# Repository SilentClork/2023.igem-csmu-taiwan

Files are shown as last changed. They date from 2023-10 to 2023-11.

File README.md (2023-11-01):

# 2023.igem-csmu-taiwan

**iGEM Hardware & Software Open-Source Project**
Welcome to the open-source hardware and software project by the CSMU-Taiwan team for the iGEM competition. Our aim is to provide a straightforward, reliable, and low-cost spectrophotometer solution that not only meets experimental requirements but also serves as an educational tool.

Project Structure and Content
**1. Espec - Professional Spectrophotometer Software**
EspecIonic:
An application developed with the Ionic framework, yet to be launched on the App Store or Google Play.

EspecWeb:
A version of Espec rewritten using HTML, its functionality is identical to the Ionic version.

Espec_User_Guide.pdf:
User guide for the Espec software.

**2. ver1_ResistanceMonitor_ArduinoR3 - Initial Hardware Design**
3D_Components:
3D design files for the first-generation hardware.

Arduino_Code:
Code for the Arduino Uno.

Assembly_Guide:
Assembly and usage guide for the hardware.

**3. ver2_LightMeasurement_ESP32 - Advanced Hardware Design**
3D_Components:
3D design files for the second-generation hardware.

Arduino_Code: Contains the code for the ESP32. This includes:
  - `ver2_LightMeasurement_ESP32.ino`: The initial version requiring Wi-Fi connectivity.
  - `ver2-2_LightMeasurement_ESP32_NoWIFI.ino`: An updated version that operates without the need for Wi-Fi connectivity, suitable for environments lacking network infrastructure.

Assembly_Guide:
Assembly and usage guide for the hardware.

**Open-Source License**
This project is licensed under the MIT License. For detailed information, please refer to the LICENSE.txt file.

**How to Contribute**
We eagerly look forward to your participation! If you have any suggestions or improvements for this project, please submit a pull request or open an issue.

**Contact Us**
If you have any questions or suggestions, please feel free to contact us via the following email: twcsmu.igem2023@gmail.com

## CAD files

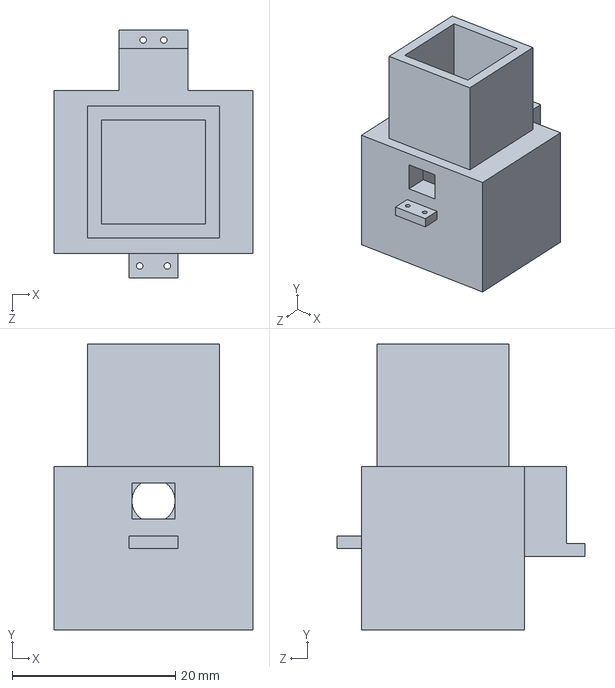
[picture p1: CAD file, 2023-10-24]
ver1_ResistanceMonitor_ArduinoR3/3D_Components/ver1-cuvette-slot.SLDPRT
24.3 x 35.0 x 30.4 mm

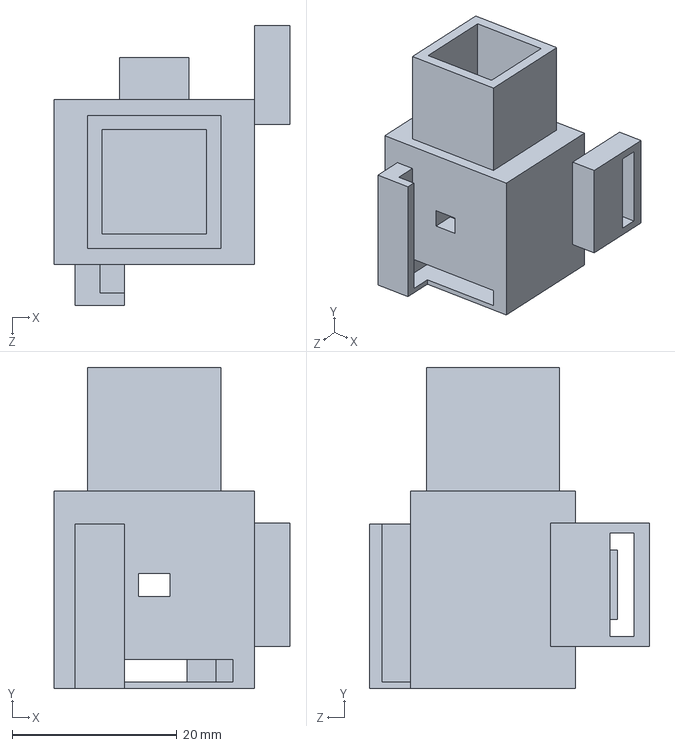
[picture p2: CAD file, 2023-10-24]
ver2_LightMeasurement_ESP32/3D_Components/ver2-cuvette-slot.SLDPRT
28.6 x 39.0 x 34.0 mm

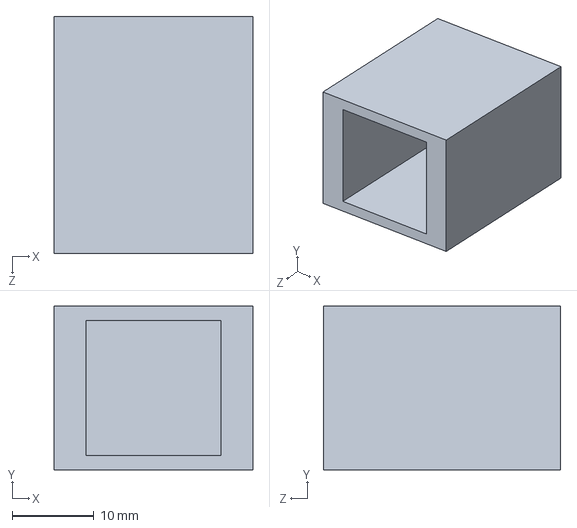
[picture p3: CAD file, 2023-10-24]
ver1_ResistanceMonitor_ArduinoR3/3D_Components/cuvette-lid.SLDPRT
24.3 x 20.0 x 29.0 mm

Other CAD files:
ver1_ResistanceMonitor_ArduinoR3/3D_Components/cuvette-lid.STL
ver1_ResistanceMonitor_ArduinoR3/3D_Components/ver1-cuvette-slot.STL
ver2_LightMeasurement_ESP32/3D_Components/ver2-cuvette-slot.STL

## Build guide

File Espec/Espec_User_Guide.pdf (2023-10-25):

## Espec Software User Guide

Introduction

Welcome to Espec, a pioneering software designed to enhance the functionality of

second-generation spectrophotometer hardware. Crafted with the core principles of

the iGEM spirit, Espec aims to streamline and simplify spectrophotometry for both

novices and experts.

Prerequisites

Software License: Espec is open-source software, released under the MIT License.

Copyright (c) 2023 by CSMU-Taiwan.

Required Hardware: Second-generation spectrophotometer setup as detailed in the

corresponding hardware assembly guide.

Getting Started

1. Initiating Espec:
- Launch the Espec application.
2. Connection to Arduino:
- Enter the IP address of the ESP32.
- The software will validate the IP and provide options to reconnect if

any discrepancies arise.

3. LED Customization:
- Users can select from red, green, or blue LEDs based on their

experimental needs.

4. Data Harvesting from Arduino:
- The software retrieves data every 5 seconds.
- Data categories displayed include illumination, blank, test, and

computational values.

5. Calibration Curve Insights:
- Users can add, save, or delete data points.
- Options to clear all data or generate a trendline for in-depth analysis

are available.

6. Trendline Data Exposition:

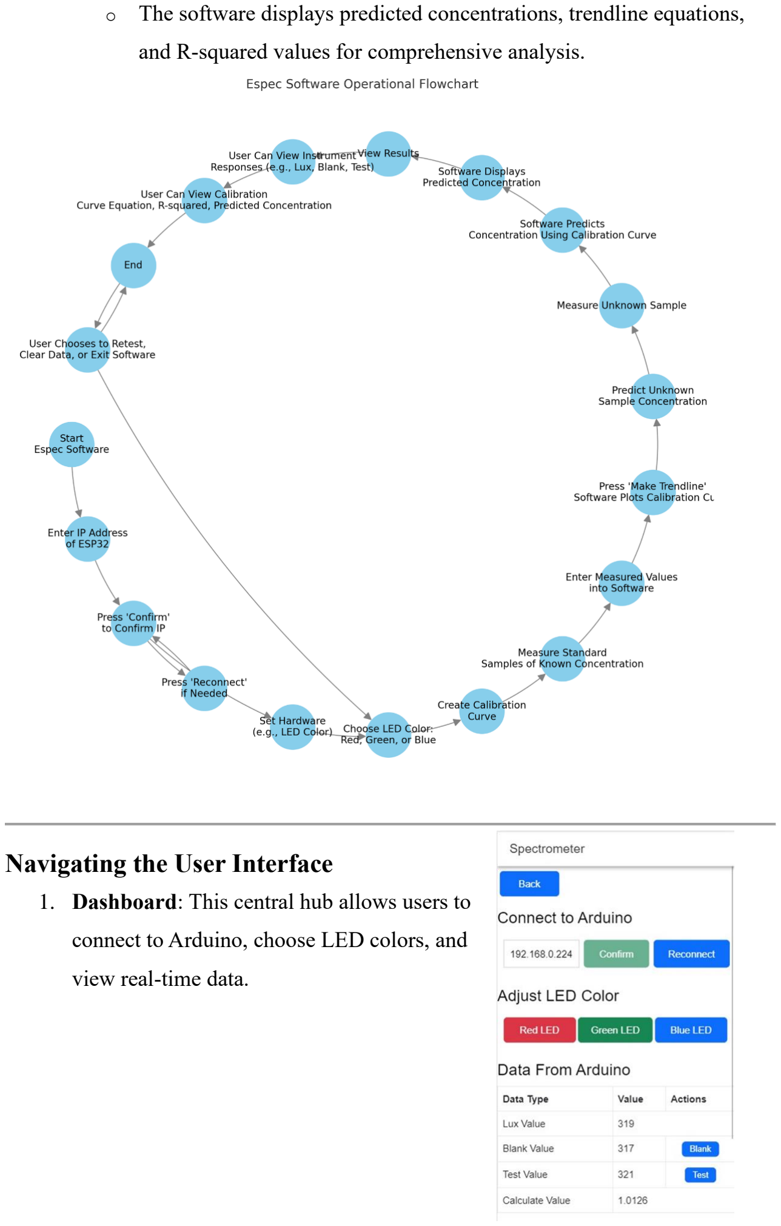
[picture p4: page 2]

- The software displays predicted concentrations, trendline equations,

and R-squared values for comprehensive analysis.

Navigating the User Interface

1. Dashboard: This central hub allows users to

connect to Arduino, choose LED colors, and

view real-time data.

2. Data Visualization and Trendline

Analysis: Transform raw data into

insightful graphs and trendlines.

Customize, save, or reset visual

representations based on user

preferences.

Limitations & Future Prospects

While Espec offers a plethora of features, it's

primarily optimized for second-generation

hardware. Future updates seek to expand

device compatibilities and integrate more

advanced features based on user feedback. Conclusion & Acknowledgments

Espec is a testament to the potential of open-

source solutions in synthetic biology research.

As we embark on this journey, we extend our

gratitude to the iGEM community for their

continuous support and inspiration. We invite

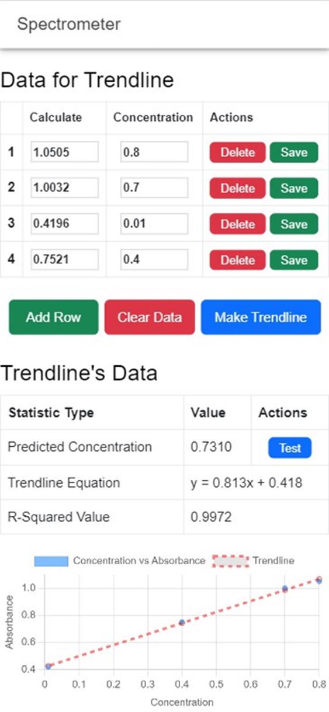
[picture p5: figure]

everyone to test Espec and contribute to its evolution.

Acknowledgments:

This software was developed by the 2023 CSMU-Taiwan iGEM team. We extend our

gratitude to our team members, advisors, and the broader iGEM community for their

invaluable feedback and support.

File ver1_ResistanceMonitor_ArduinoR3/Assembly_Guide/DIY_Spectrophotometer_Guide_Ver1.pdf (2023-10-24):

## Simple Spectrophotometer Assembly Guide (Ver1)

License: This assembly guide is open-source and is licensed under the MIT License.

Copyright (c) 2023 CSMU-Taiwan.

Material List

Quantity | Item | Description
1 | Uno R3 Board | Arduino UNO R3 development board used for programming and controlling connected components.
1 | Uno R3 USB Cable | For connecting the Uno R3 board to a computer and uploading the code.
1 | LCD 1602 12C (Liquid Crystal Display) | For displaying information.
4 | Dupont Cable Male-Female | For connecting various components.
7 | Dupont Cable Male-Male | For connecting various components.
1 | 220 Ohm Resistor | Resistor used to limit current, protecting the LED.
1 | 10,000 Ohm Resistor | Resistor used to limit current.
1 | LED | Used as a light source.
1 | Photoresistor | A resistor that senses light intensity.
1 | 3D-printed cuvette Slot Ver1 | To secure the LED, photoresistor, and cuvette.
1 | 3D-printed cuvette Lid | Acts as a lid for the slot, reducing the effect of external light on the photoresistor's readings.
1 | Cardboard Box | To package and protect the components.
1 | Electric Tape | For insulation and protection of connections.
1 | Clay | To fix or fill the components.

Assembly Steps

1. Install LED and Photoresistor into the 3D Slot: Ensure you're clear about the

correct orientation and position of the 3D slot, and that the LED and

photoresistor are placed correctly and securely.

2. Mount the Breadboard: Attach the 3D slot to the breadboard, ensuring it is

stable and aligned perfectly with the slot.

3. Connect Wires, Resistors, and Attach to the Board:
- Use Dupont cables to connect the Uno R3 board to the LCD 1602

liquid crystal display.

- Attach the 220 Ohm and 10,000 Ohm resistors to their appropriate

positions.

- Ensure the LED and photoresistor are also connected to the

breadboard.

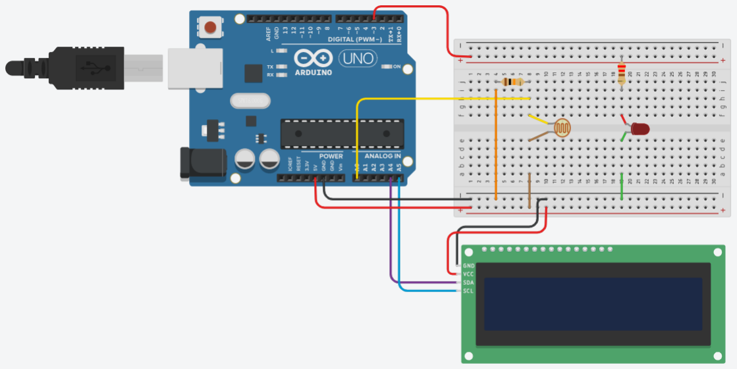
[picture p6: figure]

4. Upload Code & Ensure Functionality:
- Connect the Uno R3 board to a computer using the USB cable.
- Upload the appropriate code to the Uno R3 board.
- Ensure the LCD, LED, and photoresistor are functioning as intended.
5. Cut the Box: Based on the dimensions and shape of the 3D slot and other

components, cut the cardboard box to ensure they fit properly.

6. Handle with Electric Tape: Wrap all exposed connections and wires with

electric tape to prevent any risk of short-circuiting.

7. Place in Box & Secure with Clay:
- Place all the components and the 3D slot into the cut cardboard box.
- Use clay to secure the components, ensuring they remain stable inside

the box.

Upon completing the above steps, your simple spectrophotometer should be

assembled successfully and ready for operation. Ensure safety during use, and avoid

any short-circuits or potential hazards.

Additional Information:

- The STL and Solidworks files for the cuvette slot and lid have been provided.
- The Arduino code necessary for the operation of the spectrophotometer has

also been provided. Ensure that you upload the code to the Uno R3 board

using the Arduino IDE or a similar platform.

License Note:

This documentation and the associated files are distributed under the terms of the MIT

License. Any use, modification, or distribution of this work should comply with the

stipulations of this license. For the full license text, please refer to the accompanying

LICENSE file or visit the official MIT License web page. (https://opensource.org/licenses/MIT)

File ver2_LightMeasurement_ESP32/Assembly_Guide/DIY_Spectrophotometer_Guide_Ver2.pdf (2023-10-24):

## Simple Spectrophotometer Assembly Guide (Ver2)

Material List
Quantity | Item | Description

Electronic Components
1 | ESP32 | A powerful microcontroller with Wi-Fi & Bluetooth capabilities for more advanced applications.
1 | LCD 1602 12C (LCD Screen) | For displaying information.
1 | RGB LED | Multi-color LED used as a light source.
1 | BH1750 | A digital light sensor that provides accurate and consistent illuminance readings.
2 | Button | For user input and control.
Wires
12 | Dupont Wire (Male-Female) | For connecting various components.
12 | Dupont Wire (Male-Male) | For connecting various components.
| Miscellaneous
1 | Cardboard Box | To package and protect the components.
1 | Tape | For insulation and protection of connections.

Assembly Steps:
1. Connect the LCD Screen:
- Connect the LCD with I2C interface to the SDA and SCL pins of your ESP32 board.
- VCC to ESP32 5V
- GND to ESP32 GND
- SDA to appropriate SDA pin (depends on the ESP32 board model)
- SCL to appropriate SCL pin (depends on the ESP32 board model)
2. Connect the BH1750 Light Sensor:
- Attach the BH1750 light sensor to the same SDA and SCL pins as the LCD for I2C communication.
3. Connect the RGB LED:
- Connect the RGB LED to the defined digital pins (PIN_RED, PIN_GREEN, and PIN_BLUE).

4. Set Up the Buttons:
- Attach the buttons or switches to BUTTON_PIN1 and BUTTON_PIN2 on the ESP32.
5. Wi-Fi Connectivity:
- Ensure the ESP32 is connected to your Wi-Fi network using the provided SSID and password.
Special Notes:
- Ensure you use pull-up resistors for the I2C connection if your module doesn't come with them.
- Carefully check power connections to avoid damaging any components.

Associated Files:
- STL and Solidworks files for the cuvette slot and lid have been provided to ensure compatibility with the new components.
- The Arduino code is essential for the proper functioning of this hardware version. It's designed to interact with software for a more integrated and comprehensive user experience. Ensure that you upload the provided code to the ESP32 using the Arduino IDE or a similar platform.

License Note:

This documentation and the associated files are distributed under the terms of the MIT

License. Any use, modification, or distribution of this work should comply with the

stipulations of this license. For the full license text, please refer to the accompanying

LICENSE file or visit the official MIT License web page. (https://opensource.org/licenses/MIT)

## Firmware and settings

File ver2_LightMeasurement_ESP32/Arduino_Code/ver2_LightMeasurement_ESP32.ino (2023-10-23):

/*
 * Open-source Arduino Light Measurement System
 * 
 * Hardware Assembly:
 * 1. Connect an LCD with I2C interface to the SDA and SCL pins of your Arduino board.
 *    - VCC to Arduino 5V
 *    - GND to Arduino GND
 *    - SDA to appropriate SDA pin (depends on the board model)
 *    - SCL to appropriate SCL pin (depends on the board model)
 * 2. Connect the BH1750 light sensor to the same SDA and SCL pins for I2C communication.
 * 3. Connect LEDs or other indicators to digital pins defined (PIN_RED, PIN_GREEN, and PIN_BLUE).
 * 4. Connect buttons or switches to BUTTON_PIN1 and BUTTON_PIN2.
 * 5. Ensure the board is connected to the Wi-Fi network using provided SSID and password.
 * 
 * Before you begin:
 * - Please ensure you provide your own Wi-Fi SSID and password below.
 * - Do NOT share or commit your actual Wi-Fi credentials in the code for security reasons.
 * 
 * Instructions:
 * 1. Replace 'YOUR_WIFI_SSID' with your actual Wi-Fi SSID.
 * 2. Replace 'YOUR_WIFI_PASSWORD' with your actual Wi-Fi password.
 * 3. Follow the rest of the instructions provided in the code or documentation.
 * 
 * Note:
 * - Make sure to use pull-up resistors for the I2C connection if your module doesn't have them.
 * - This code is open-source and can be modified and shared freely, but please attribute the original author.
 * - Ensure your power connections are correct to avoid damaging your components.
 * 
 * Author: CSMU-Taiwan
 * 
 * --- LICENSE INFORMATION ---
 * Copyright (c) 2023 CSMU-Taiwan
 * Licensed under the MIT License. 
 * For the full license text, please see the LICENSE file in the project root.
 */

 
#include <Wire.h>
#include <BH1750.h>
#include <LiquidCrystal_I2C.h>
#include <math.h>
#include <WiFi.h>

#define PIN_RED    4
#define PIN_GREEN  2
#define PIN_BLUE   15
const int BUTTON_PIN1 = 23;
const int BUTTON_PIN2 = 19;
const long buttonInterval = 200;
const long lightInterval = 2000;

const char* ssid = "YOUR_WIFI_SSID";
const char* password = "YOUR_WIFI_PASSWORD";
WiFiServer server(8080);

BH1750 lightMeter(0x23);
LiquidCrystal_I2C lcd(0x27, 16, 2);

uint16_t BlankResult = 0;
uint16_t TestResult = 0;
double CalculateResult = 0;
String lastMode = "";
double lastCalcResult = 0.0;
unsigned long previousButtonMillis = 0;
unsigned long previousLightMillis = 0;
char buffer[50];

struct DataToSend {
  int lux = 0;
  int blk = 0;
  double cal = 0;
  int tst = 0;
};
DataToSend dataToSend;

void BlankFunction();
double TestFunction();
uint16_t getAverageLux();
void readAndDisplayLightLevel();
void handleButton(int, const char*);
void handleClient(String RequestLine, WiFiClient client, String key1, int value1, String key2, int value2, String key3, double value3, String key4, int value4);
void sendJSONData(WiFiClient client, String key1, int value1, String key2, int value2, String key3, double value3, String key4, int value4);

void setup() {
    Serial.begin(115200);
    delay(1000);
    WiFi.mode(WIFI_STA);
    WiFi.begin(ssid, password);

    while (WiFi.status() != WL_CONNECTED) {
        delay(100);
    }

    lcd.begin();
    lcd.backlight();
    lcd.clear();
    lcd.setCursor(0, 1);
    lcd.print("IP:");
    lcd.print(WiFi.localIP());
    Wire.begin();
    lightMeter.begin();

    pinMode(BUTTON_PIN1, INPUT_PULLUP);
    pinMode(BUTTON_PIN2, INPUT_PULLUP);
    pinMode(PIN_RED, OUTPUT);
    pinMode(PIN_GREEN, OUTPUT);
    pinMode(PIN_BLUE, OUTPUT);
    analogWrite(PIN_RED, 255);
    analogWrite(PIN_GREEN, 0);
    analogWrite(PIN_BLUE, 0);

    delay(10000);
    server.begin();
}

void loop() {
    unsigned long currentMillis = millis();

    if (currentMillis - previousButtonMillis >= buttonInterval) {
        previousButtonMillis = currentMillis;
        handleButton(BUTTON_PIN1, "Blank Mode On");
        handleButton(BUTTON_PIN2, "Test Mode On");
    }

    if (currentMillis - previousLightMillis >= lightInterval) {
        previousLightMillis = currentMillis;
        readAndDisplayLightLevel();
        dataToSend.lux = lightMeter.readLightLevel();
    }

    WiFiClient client = server.available();
    if (client) {
        String InitRequest = client.readStringUntil('\r');
        handleClient(InitRequest, client, "lux", dataToSend.lux, "blk", dataToSend.blk, "cal", dataToSend.cal, "tst", dataToSend.tst);
    }
}

void handleButton(int buttonPin, const char* message) {
  int buttonState = digitalRead(buttonPin);
  String currentMode;
  double currentCalcResult = 0.0;

  if (buttonState == LOW) {
    lcd.setCursor(0, 1);
    lcd.print(message);
    Serial.println(message);

    if (buttonPin == BUTTON_PIN1) {
      currentMode = "Blank Mode On";
      BlankFunction();
    } else if (buttonPin == BUTTON_PIN2) {
      currentMode = "Test Mode On";
      currentCalcResult = TestFunction();
    }

    if (currentMode != lastMode || currentCalcResult != lastCalcResult) {
      lastMode = currentMode;
      lastCalcResult = currentCalcResult;
      if (buttonPin == BUTTON_PIN1) {
        lcd.setCursor(0, 1);
        lcd.print("Blank Licht: ");
        lcd.print(BlankResult);
        lastMode = "Blank Licht: ";
      } else if (buttonPin == BUTTON_PIN2 && BlankResult != 0) {
        lcd.setCursor(0, 1);
        lcd.print("Calc: ");
        lcd.print(CalculateResult);

        int usedChars = 6 + String(CalculateResult).length();
        int remainingChars = 16 - usedChars;

        for (int i = 0; i < remainingChars; i++) {
          lcd.print(" ");
        }
        lastMode = "Calc: ";
      }
    }

    delay(2000);

  } else {
    lcd.setCursor(0, 1);
    lcd.print("                ");
    lastMode = "";
  }
}
uint16_t getAverageLux() {
  const int SAMPLES = 20;
  uint32_t totalLux = 0;
  uint16_t luxValues[SAMPLES];

  for (int i = 0; i < SAMPLES; i++) {
    luxValues[i] = lightMeter.readLightLevel();
    totalLux += luxValues[i];
    delay(50);
  }

  uint16_t avgLux = totalLux / SAMPLES;
  for (int i = 0; i < SAMPLES; i++) {
    Serial.println("lux_sample_" + String(i) + ": " + String(luxValues[i]));
  }

  return avgLux;
}


void readAndDisplayLightLevel() {
  uint16_t lux = lightMeter.readLightLevel();

  Serial.print("Licht: ");
  Serial.print(lux);
  Serial.println(" lux");

  lcd.setCursor(0, 0);
  lcd.print("Licht: ");
  lcd.print(lux);
  lcd.print(" lux   ");
}

void handleClient(String RequestLine, WiFiClient client, String key1, int value1, String key2, int value2, String key3, double value3, String key4, int value4) {
  String header;
  String request = client.readStringUntil('\r');
  String currentLine = "";

  while (client.connected()) {
    if (client.available()) {
      char c = client.read();
      Serial.write(c);
      header += c;

      if (c == '\n') {
        if (currentLine.length() == 0) {
          client.println("HTTP/1.1 200 OK");
          client.println("Content-Type: application/json");
          client.println("Access-Control-Allow-Origin: *");
          client.println("Connection: close");
          client.println();

          sendJSONData(client, key1, value1, key2, value2, key3, value3, key4, value4);

          break;
        } else {
          currentLine = "";
        }
      } else if (c != '\r') {
        currentLine += c;
      }
    }
  }
  Serial.print("RequestLine: ");
  Serial.println(RequestLine);
  if (RequestLine.indexOf("GET /blk") >= 0) {
    Serial.println("Blank");
    BlankFunction();
    client.println("HTTP/1.1 200 OK");
    client.println("Content-Type: text/plain");
    client.println("Access-Control-Allow-Origin: *");
    client.println();
    client.println("LED is OFF");
  }
  else if (RequestLine.indexOf("GET /tst") >= 0) {
    Serial.println("Test");
    TestFunction();
    client.println("HTTP/1.1 200 OK");
    client.println("Content-Type: text/plain");
    client.println("Access-Control-Allow-Origin: *");
    client.println();
    client.println("LED is OFF");
  }
  if (RequestLine.indexOf("GET /green") >= 0) {
    Serial.println("GREEN LED");
    analogWrite(PIN_RED,   0);
    analogWrite(PIN_GREEN, 255);
    analogWrite(PIN_BLUE,  0);

    client.println("HTTP/1.1 200 OK");
    client.println("Content-Type: text/plain");
    client.println("Access-Control-Allow-Origin: *");
    client.println();
    client.println("GreenLED is ON");
  }
  if (RequestLine.indexOf("GET /blue") >= 0) {
    Serial.println("BLUE LED");
    analogWrite(PIN_RED,   0);
    analogWrite(PIN_GREEN, 0);
    analogWrite(PIN_BLUE,  255);

    client.println("HTTP/1.1 200 OK");
    client.println("Content-Type: text/plain");
    client.println("Access-Control-Allow-Origin: *");
    client.println();
    client.println("BlueLED is ON");
  }
  if (RequestLine.indexOf("GET /red") >= 0) {
    Serial.println("RED LED");
    analogWrite(PIN_RED,   255);
    analogWrite(PIN_GREEN, 0);
    analogWrite(PIN_BLUE,  0);

    client.println("HTTP/1.1 200 OK");
    client.println("Content-Type: text/plain");
    client.println("Access-Control-Allow-Origin: *");
    client.println();
    client.println("RedLED is ON");
  }
  client.stop();
  Serial.println("Client disconnected.");
  Serial.println("");
}

void sendJSONData(WiFiClient client, String key1, int value1, String key2, int value2, String key3, double value3, String key4, int value4) {
  dtostrf(value3, 10, 4, buffer);
  String calcString = String(buffer);

  String jsonData = "{";
  jsonData += "\"" + key1 + "\":" + String(value1) + ",";
  jsonData += "\"" + key2 + "\":" + String(value2) + ",";
  jsonData += "\"" + key3 + "\":" + calcString + ",";
  jsonData += "\"" + key4 + "\":" + String(value4);
  jsonData += "}";

  client.println(jsonData);
  Serial.println("JSON data sent: " + jsonData);
}
void BlankFunction() {
  lcd.setCursor(0, 1);
  lcd.print("Blanking...     ");
  Serial.println("Blanking...     ");
  BlankResult = getAverageLux();
  Serial.print("Blank: ");
  Serial.print(BlankResult);
  Serial.println(" lux");
  dataToSend.blk = BlankResult;
  lcd.setCursor(0, 1);
  lcd.print("Blank Licht: ");
  lcd.print(BlankResult);
}
double TestFunction() {
  double currentResultInFunction = 0.0 ;
  Serial.println(BlankResult);
  if (BlankResult != 0) {
    lcd.setCursor(0, 1);
    lcd.print("Testing...     ");
    Serial.println("Testing...     ");
    TestResult = getAverageLux();

    double logTestResult = log10(TestResult);
    double logBlankResult = log10(BlankResult);
    CalculateResult = logBlankResult - logTestResult;
    currentResultInFunction = CalculateResult;
    dtostrf(CalculateResult, 10, 4, buffer);
    String calcString = String(buffer);

    Serial.print("Test: ");
    Serial.print(TestResult);
    Serial.println(" lux");
    Serial.print("Calculate: ");
    Serial.print(calcString);
    Serial.println(" lux");

    dataToSend.cal = CalculateResult;
    dataToSend.tst = TestResult;

    lcd.setCursor(0, 1);
    lcd.print("Calc: ");
    lcd.print(calcString);
  }
  else {
    lcd.setCursor(0, 1);
    lcd.print("Please Blank");
    Serial.println("Please Blank");
    delay(2000);
    lcd.setCursor(0, 1);
    lcd.print("                ");
  }
  return currentResultInFunction;
}

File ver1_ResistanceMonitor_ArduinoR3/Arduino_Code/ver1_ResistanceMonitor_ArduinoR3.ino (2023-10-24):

/*
 * Open-source Arduino Resistance Monitor
 * 
 * Hardware Assembly:
 * 1. Connect an LCD with I2C interface to the SDA and SCL pins of your Arduino board.
 *    - VCC to Arduino 5V
 *    - GND to Arduino GND
 *    - SDA to Arduino SDA (often A4)
 *    - SCL to Arduino SCL (often A5)
 * 2. Connect the resistance sensor to analog pin A0.
 * 3. Connect a LED or similar device to digital pin 3 to indicate when the Arduino is reading the resistance.
 * 
 * Note:
 * - Make sure to use pull-up resistors for the I2C connection if your module doesn't have them.
 * - This code is open-source and can be modified and shared freely, but please attribute the original author.
 * - Ensure your power connections are correct to avoid damaging your components.
 * 
 * Author: CSMU-Taiwan
 * 
 * --- LICENSE INFORMATION ---
 * Copyright (c) 2023 CSMU-Taiwan
 * Licensed under the MIT License. 
 * For the full license text, please see the LICENSE file in the project root.
 */

#include <Wire.h>                // Include the Wire library for I2C communication
#include <LiquidCrystal_I2C.h>  // Include the LiquidCrystal library for I2C LCDs

// Define constants for LCD configuration
const int LCD_ADDRESS = 0x27;   // I2C address of the LCD
const int LCD_COLUMNS = 16;     // Number of columns in the LCD
const int LCD_ROWS = 2;         // Number of rows in the LCD

// Initialize the LiquidCrystal object with the above constants
LiquidCrystal_I2C lcd(LCD_ADDRESS, LCD_COLUMNS, LCD_ROWS);

void setup() {
  Serial.begin(9600);           // Start the serial communication at 9600 baud rate
  pinMode(3, OUTPUT);           // Set pin 3 as an OUTPUT
  
  lcd.begin();                  // Initialize the LCD
  lcd.backlight();              // Turn on the backlight of the LCD
  
  displayMessage("Hello iGEM !", "");  // Display a welcome message on the LCD
  delay(2000);                  // Wait for 2 seconds
}

void loop() {
  int resistanceValue = analogRead(A0);  // Read the analog value from pin A0
  digitalWrite(3, HIGH);                // Set pin 3 to HIGH

  // Print the resistance value to the serial monitor
  Serial.print("Resistance: ");
  Serial.print(resistanceValue);
  Serial.println(" ohm");

  displayResistance(resistanceValue);  // Display the resistance value on the LCD

  delay(1000);   // Wait for 1 second before the next loop iteration
}

/**
 * Displays a message on the LCD.
 * @param line1: The message to display on the first line of the LCD.
 * @param line2: The message to display on the second line of the LCD.
 */
void displayMessage(String line1, String line2) {
  lcd.clear();                 // Clear the LCD screen
  lcd.setCursor(0, 0);         // Set the cursor to the beginning of the first line
  lcd.print(line1);            // Print the first message
  lcd.setCursor(0, 1);         // Set the cursor to the beginning of the second line
  lcd.print(line2);            // Print the second message
}

/**
 * Displays a resistance value on the LCD.
 * @param value: The resistance value to display.
 */
void displayResistance(int value) {
  displayMessage("Resistance:", String(value) + " Ohm");  // Use the displayMessage function to show the resistance value
}
